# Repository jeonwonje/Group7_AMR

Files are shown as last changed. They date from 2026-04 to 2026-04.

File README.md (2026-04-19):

# Group 7 — Autonomous Mobile Robot (AMR)

> CDE2310 Engineering Systems Design · AY25/26 Semester 2 · NUS EDIC

A **TurtleBot3 Burger (MeowthBot)** ROS 2 Humble workspace for the CDE2310 warehouse delivery mission. The robot autonomously explores a maze using LiDAR-based SLAM, detects AprilTag delivery stations, docks via geometric visual servoing, and delivers ping-pong balls using a servo-driven rack-and-pinion launcher.

---

## System Design Document

The full SDD is split across eight files under [`docs/`](docs/) — one per G2 section. Start with the ConOps, skim the HLD, and jump into the subsystem / ICD detail as needed.

| § | Document | Covers |
|---|---|---|
| 1 | [Requirements Specification](docs/reports/requirements_specification.md) | FRs, NFRs, constraints, traceability |
| 2 | [Concept of Operations](docs/reports/conops.md) | Mission overview, operational scenarios, design selection, risks |
| 3 | [High-Level Design](docs/reports/high_level_design.md) | Architecture, data flow, hardware-software mapping, design decisions |
| 4 | [Subsystem Design](docs/reports/subsystem_design.md) | Navigation, perception, docking, delivery, mission coordination, search |
| 5 | [Interface Control Document](docs/reports/interface_control_document.md) | ROS 2 topics / services / actions, TF tree, hardware interfaces, network |
| 6 | [Software Development](docs/reports/software_development.md) | Environment, repo layout, branch policy, conventions, dependencies |
| 7 | [Testing](docs/reports/testing_documentation.md) | Strategy, integration tests, FAT, traceability, known issues |
| 8 | [End User Documentation](docs/end_user_doc/EndUserDocumentation_Group7.md) | Printed 5-page operator hand-in for the final mission |

### Hardware & Manufacturing

- [Hardware README](hardware/README.md) — mechanical design, CAD version history, materials (maintained by Daniel).
- [Manufacturing Guide](docs/MANUFACTURING.md) — Bambu Lab P2S print workflow for the team's `.3mf` files.

### Project Meta

- [`CHANGELOG.md`](CHANGELOG.md) — release history (SemVer).
- [`CLAUDE.md`](CLAUDE.md) — repo conventions for AI assistants.
- [`AGENT_GIT_GUIDE.md`](AGENT_GIT_GUIDE.md) — quick AI git reference.

---

## Quick start

```bash
# one-time build
source /opt/ros/humble/setup.bash
cd ~/Group7_AMR
colcon build
source install/setup.bash

# RPi (on the robot)
ros2 launch apriltag_docking apriltag_dock_pose_publisher.launch.py &
ros2 run CDE2310_AMR_Trial_Run delivery_server &
ros2 launch turtlebot3_bringup robot.launch.py

# Laptop (base station, same network)
export TURTLEBOT3_MODEL=burger
ros2 launch CDE2310_AMR_Trial_Run full_mission.launch.py
```

See the [End User Documentation](docs/end_user_doc/EndUserDocumentation_Group7.md) §2 for the full deployment sequence and FAT checklist.

---

## Team

| Member | Role | Branch |
|---|---|---|
| Jeon Won Je | Lead — final system integration, nav tuning, manufacturing | `dev/jeon` |
| Shashwat Gupta | Mission coordinator, docking, perception | `dev/shashwat` |
| Kuga | Navigation core | `dev/kuga` |
| Clara Ong | Delivery server, perception | `dev/clara` |
| Daniel Yow | Mechanical subsystem (hardware, CAD, manufacturing docs) | `dev/daniel` |

---

*CDE2310 · NUS College of Design and Engineering · AY25/26*

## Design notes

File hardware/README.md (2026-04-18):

# Hardware <!-- omit in toc -->

## Table of contents <!-- omit in toc -->
- [Overview](#overview)
  - [System Description](#system-description)
  - [Design Objectives](#design-objectives)
- [Initial concept development](#initial-concept-development)
  - [Rack and half pinion](#rack-and-half-pinion)
- [Design iterations](#design-iterations)
  - [Version 1.0.0 - first design](#version-100---first-design)
  - [Version 2.0.0 - servo integrated into launcher](#version-200---servo-integrated-into-launcher)
  - [Version 2.1.0 - bearing supports for rack and pinion](#version-210---bearing-supports-for-rack-and-pinion)
  - [Version 2.2.0 - clutch bearing reset](#version-220---clutch-bearing-reset)
  - [Final Performance summary](#final-performance-summary)
- [Key mechanism explanations](#key-mechanism-explanations)
  - [Rubber band vs Spring](#rubber-band-vs-spring)
  - [Clutch bearing reset](#clutch-bearing-reset)
  - [Rack and pinion engagement](#rack-and-pinion-engagement)
- [Materials and Components](#materials-and-components)
- [Limitations and application specific modifications](#limitations-and-application-specific-modifications)
  - [Launcher System](#launcher-system)

## Overview

This repository contains the CAD models for the payload
and mounting systems used in the AMR.

### System Description

The payload system consists of:

1. Mounting plate 
2. Camera Mount  
3. Launcher
4. Launcher mount 
5. Ball feeder

---

### Design Objectives

- Maintain robot size as much as possible
- Ensure unobstructed LiDAR view
- Position camera at optimal location for docking
- Minimize overall center of gravity
- Ensure repeatability of launcher

---
## Initial concept development

### Rack and half pinion

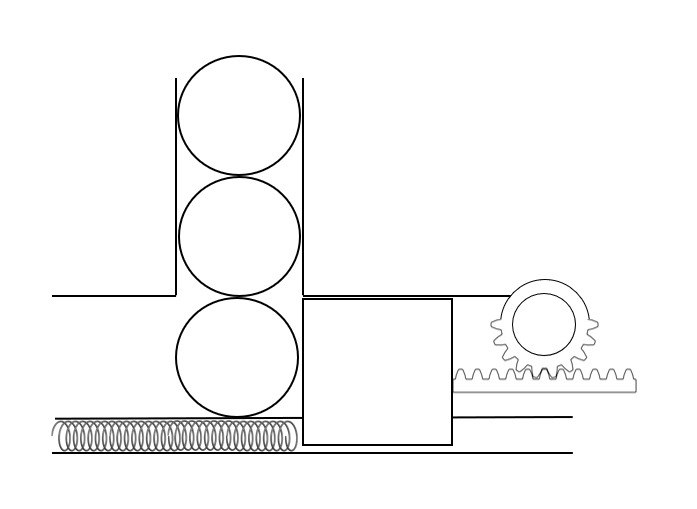
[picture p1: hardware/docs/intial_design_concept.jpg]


Concept Description

The proposed concept used a rack and half-pinion mechanism powered by a continuous rotation servo motor.

At the beginning of each cycle:

- The pinion rotates and engages the rack.
- The rack is pulled backward, retracting the plunger.
- As the plunger retracts, a ball falls into the loading position.

Once the pinion reaches the end of its rotation:

- The rack is released.
- Stored elastic energy in the rubber band drives the plunger forward.
- The ball is launched.

After launch:

- The plunger returns to its forward position.
- This forward position temporarily blocks the next ball from loading prematurely.
- This allows controlled loading of one ball per cycle.

This mechanism enabled both loading and launching to be performed using a single rotational motion.

Rationale for Choosing This Concept:

- This concept was selected due to its ability to combine multiple functions into a single mechanism.

Key advantages included:

- Single actuator operation
- Only one servo motor was required to both retract and release the plunger, reducing system complexity.
- Compact design
- The rack and pinion arrangement allowed the launcher to be positioned within a limited space.
- Low power requirements
- The use of elastic energy storage reduced the need for continuous motor torque during launching.
- Simple mechanical layout
- Fewer moving components reduced potential points of failure.

This made the design suitable for integration into the constrained mechanical layout of the robot.

Identified Limitations of Initial Concept:

Despite its advantages, several limitations were identified during early evaluation.

- Limited launch range
- The amount of stored elastic energy was restricted by the available rack travel distance.
- Potential alignment sensitivity
- Rack and pinion mechanisms require accurate alignment to prevent slipping or uneven wear.
- Dependence on consistent pinion engagement
- Incorrect starting positions could lead to failed engagement or inconsistent loading.

These limitations informed the design changes introduced in later iterations.

## Design iterations
### Version 1.0.0 - first design
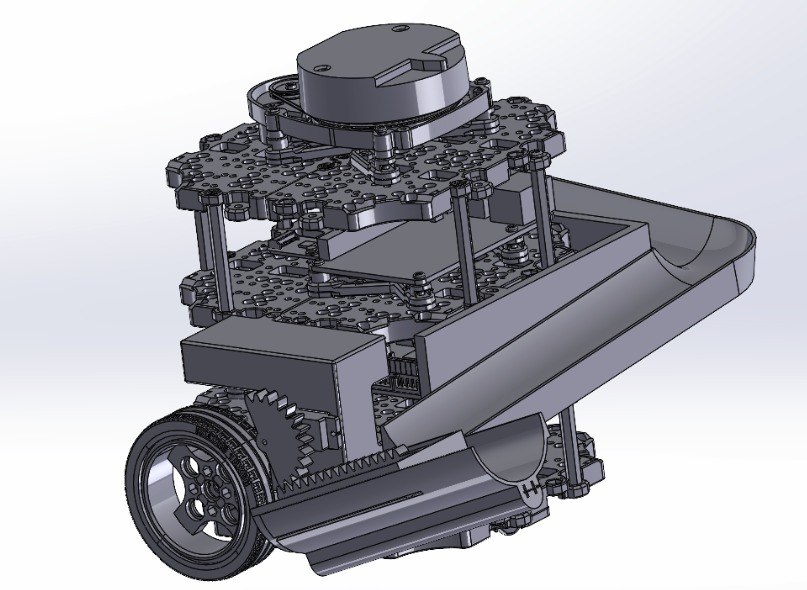
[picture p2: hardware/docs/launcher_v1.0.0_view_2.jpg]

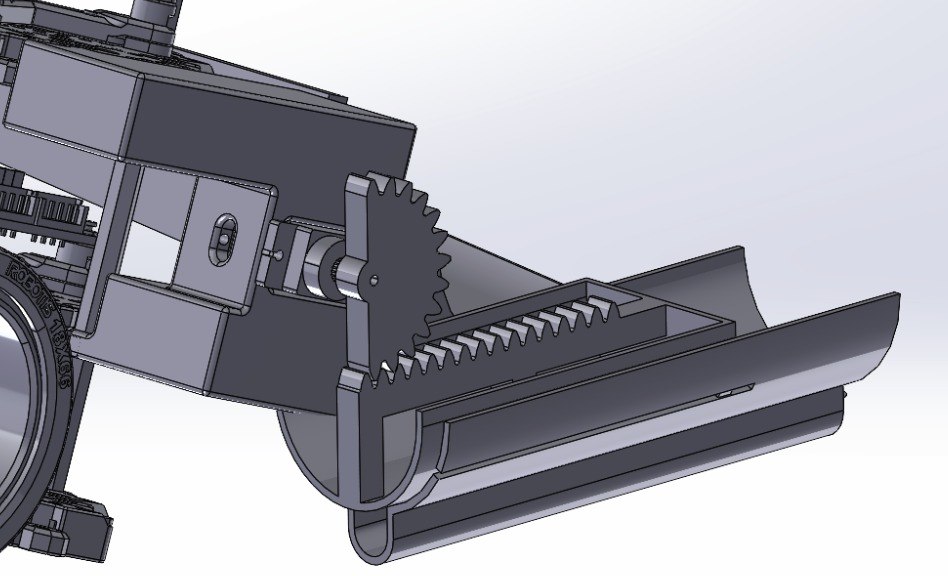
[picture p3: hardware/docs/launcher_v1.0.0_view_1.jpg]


Problems Observed:

- The servo was mounted directly to the chassis instead of the launcher assembly.
This caused structural flexing during operation, leading to misalignment between the pinion and rack and resulting in slipping.
- Mounting the servo on the chassis also prevented independent testing of the launcher mechanism.
This slowed down development because launcher testing depended on Turtlebot availability.
- Nav team feedback that current poition of launcher would make moving through the maze challenging.

### Version 2.0.0 - servo integrated into launcher
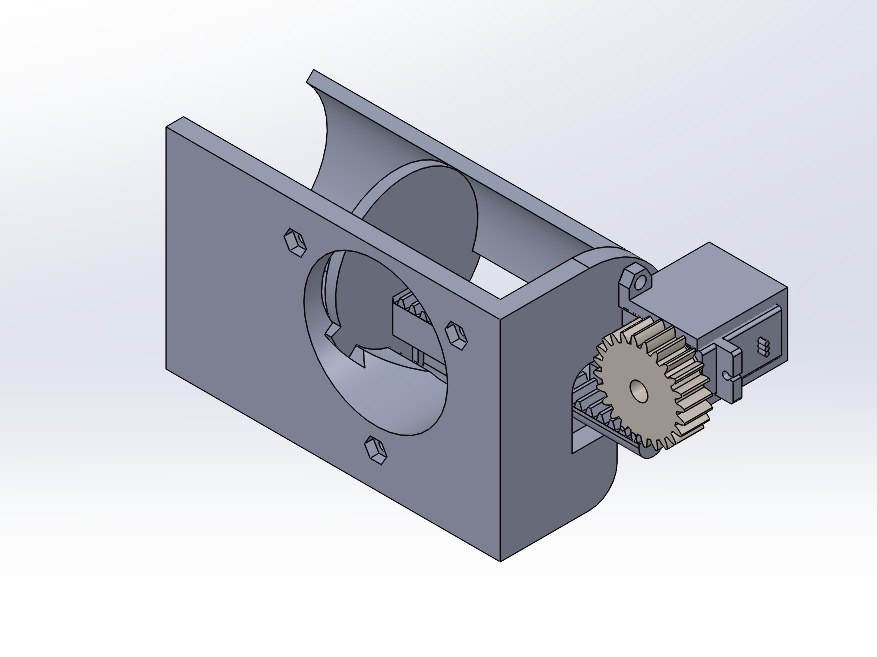
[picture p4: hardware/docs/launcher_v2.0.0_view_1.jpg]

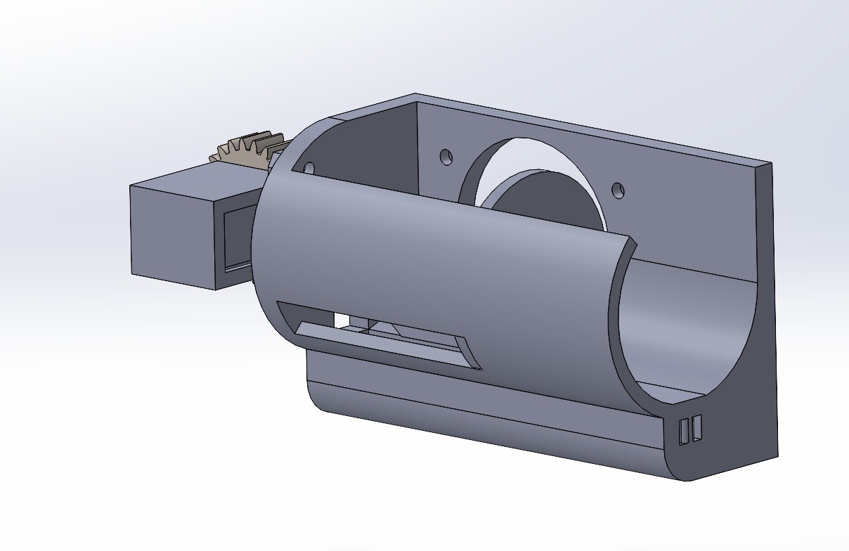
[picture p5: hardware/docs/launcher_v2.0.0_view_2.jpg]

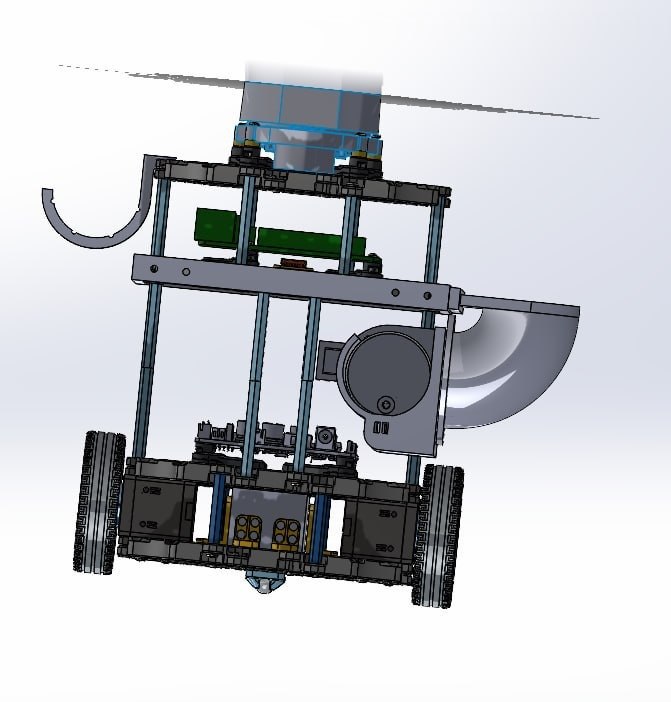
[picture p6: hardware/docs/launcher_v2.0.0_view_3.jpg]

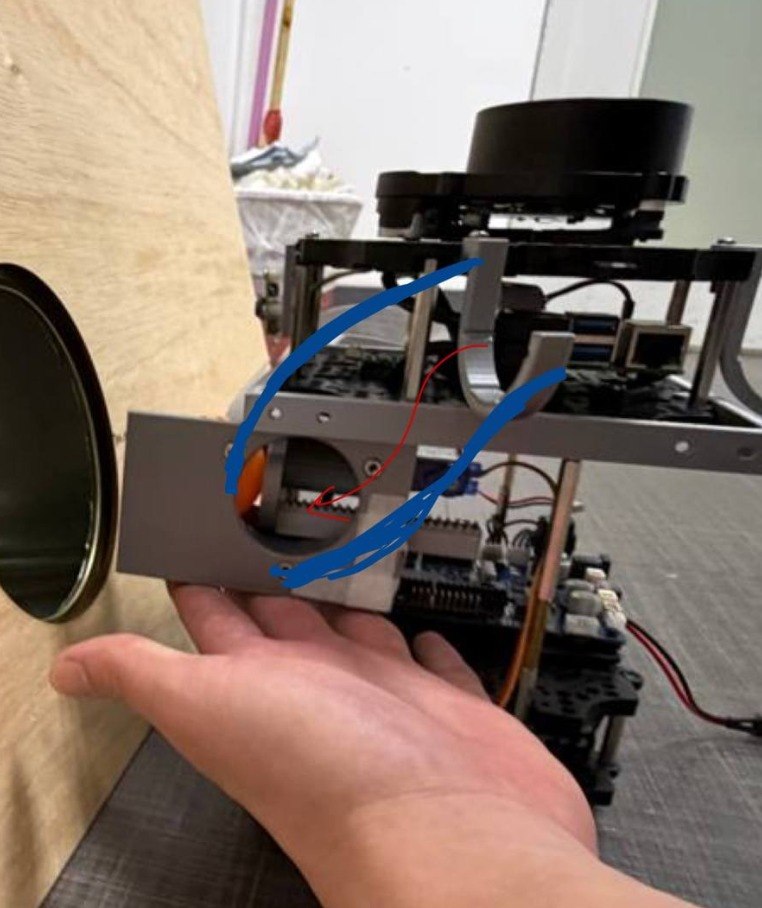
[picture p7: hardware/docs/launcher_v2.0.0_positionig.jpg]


Changes from Previous Version:

- Mounted the servo directly onto the launcher assembly to reduce structural flex.
- Repositioned the launcher between waffle plates instead of side-mounted to improve structural support.

Problems Observed:

- Launcher achieved poor range, indicating insufficient stored energy and inefficiencies.
- The plunger occasionally became stuck and failed to release.
- Pinion slipping issue persisted due to insufficient constraint of both rack and pinion.
- When assembling putting plunger into tube was challenging.

Possible Root Causes:

- Rack alignment was not properly constrained.
- Pinion support was only provided on one side, allowing tilting under load.
- The plunger face and rack being one piece makes it hard and awkward to fit into the tube.

### Version 2.1.0 - bearing supports for rack and pinion
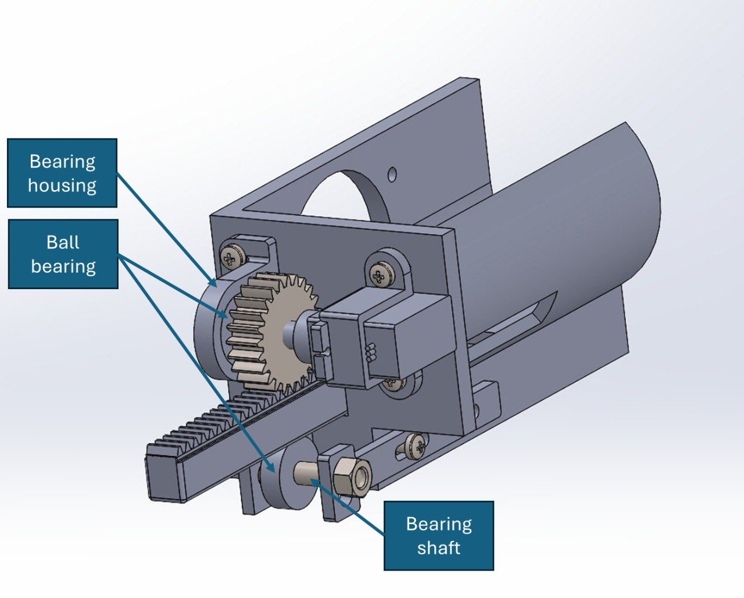
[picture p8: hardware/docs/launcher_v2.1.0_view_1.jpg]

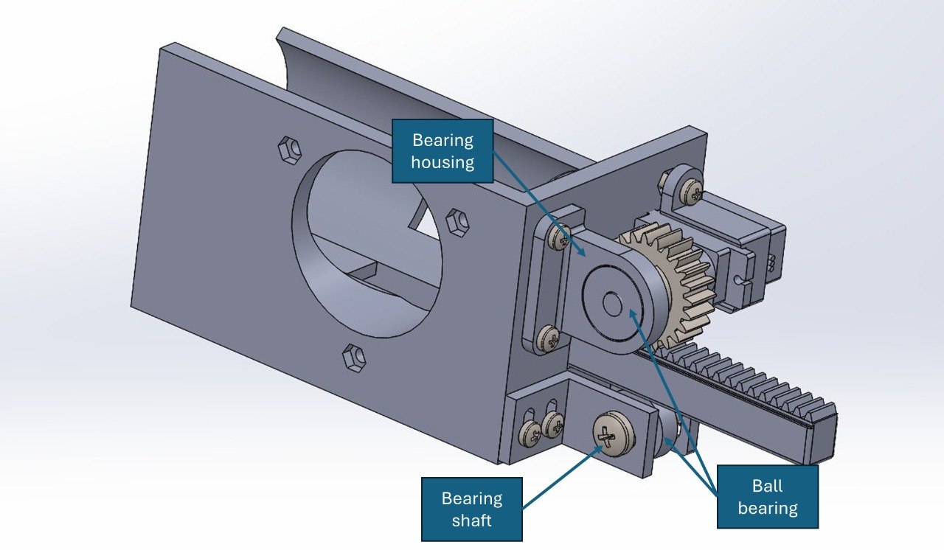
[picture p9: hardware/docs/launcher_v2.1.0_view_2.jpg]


Changes from Previous Version:
- Added a ball bearing and housing to support the pinion from the opposite side, improving alignment and reducing tilting.
- Added a shaft and bearing system beneath the rack to prevent downward movement during loading.
- Replaced the spring with a rubber band to increase stored elastic energy while keeping motor torque below stall limits.
- Split plunger into plunger face and rack to be fastened together with M3 screw.

Problems Observed:
- Pinion position after each launch is inconsistent.

Possible root causes:
- Continuous servo does not have rotation control
- Tuning each rotation by time is difficult and impractical
- Rotation error after each launch stacks up 

### Version 2.2.0 - clutch bearing reset
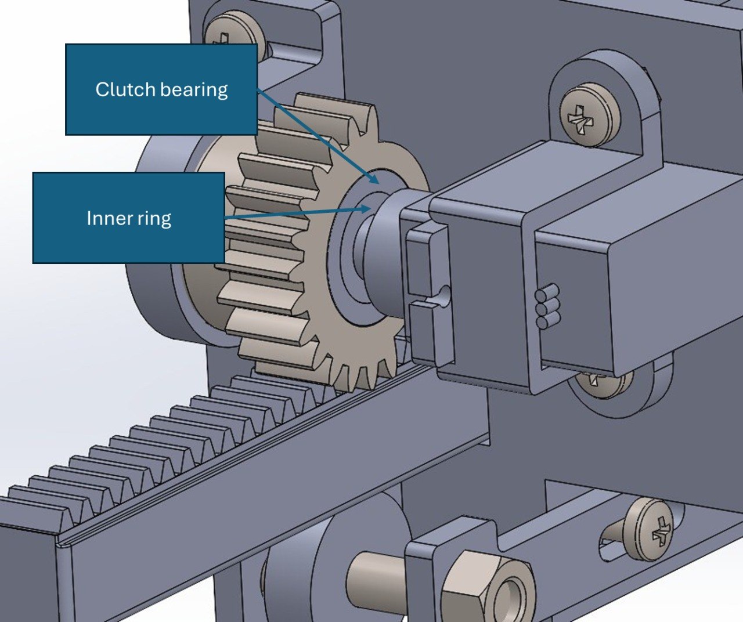
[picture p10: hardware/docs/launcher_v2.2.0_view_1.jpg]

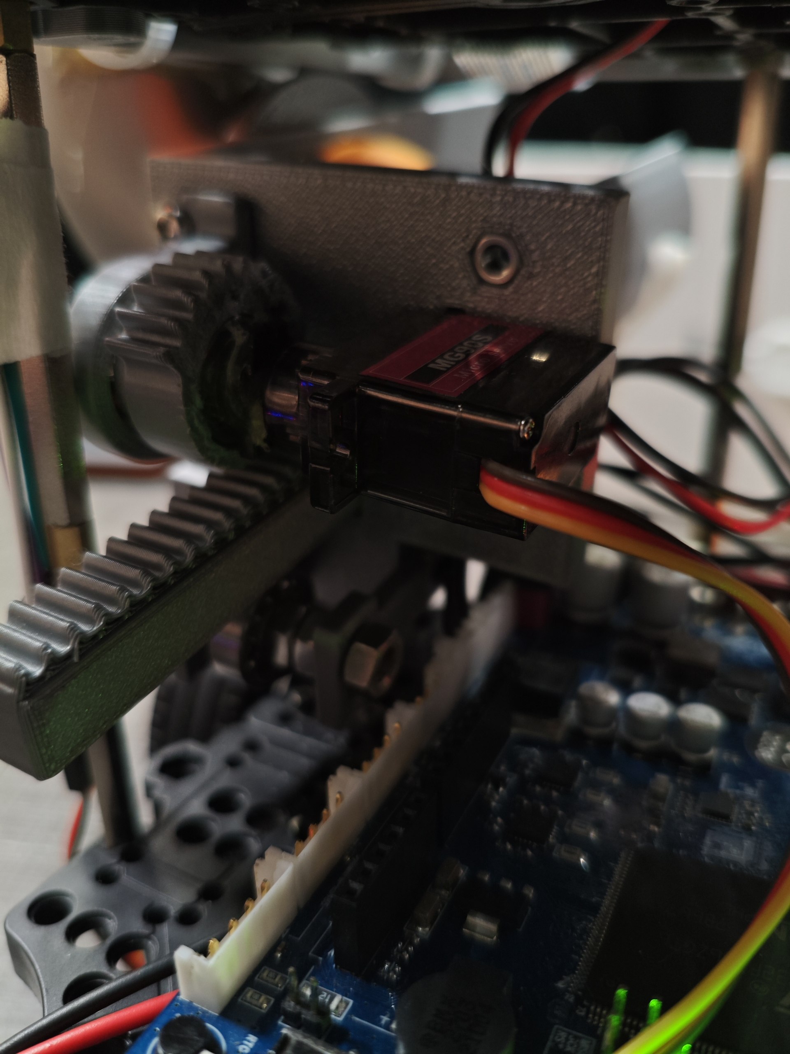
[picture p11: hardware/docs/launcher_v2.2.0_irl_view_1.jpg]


Changes from Previous Version:

- Added a clutch bearing and inner ring to allow the pinion to reset to a consistent starting position after each launch.
- Modified the pinion design to house the clutch bearing internally.

Problems Observed:

- Engagement between the pinion and rack occurred at inconsistent positions.
- In some cases, the plunger was already fully retracted before rack was released

Fix Implemented:

- Added washers between the plunger face and rack to shift the rack starting position.

Result After Fix:

- Engagement between pinion and rack became consistent.

### Final Performance summary
- No slippage between rack and pinion during repeated testing
- Consistent engagement between rack and pinion
- Pinion achieves consistent reset position
- Plunger motion is smooth and repeatable

## Key mechanism explanations

### Rubber band vs Spring
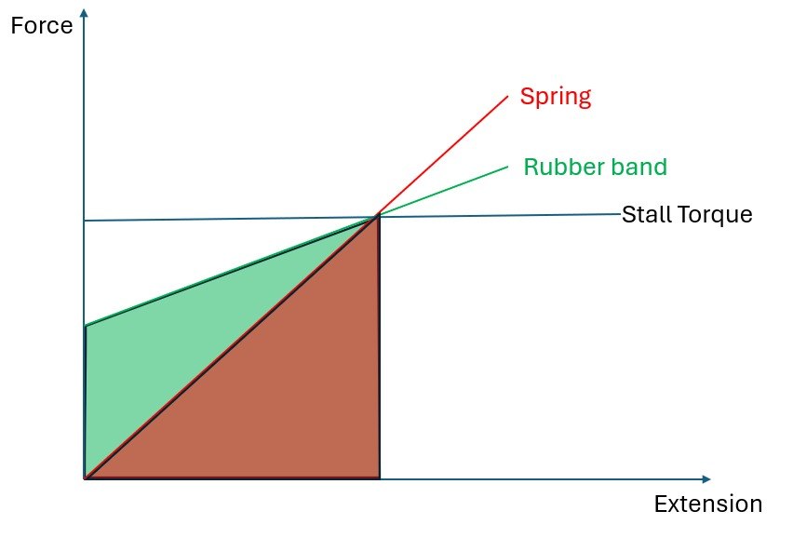
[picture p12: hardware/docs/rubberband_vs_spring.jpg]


Rubber band can be already be streched when the plunger is in the fowardmost position allowing us to store more energy while keeping within the stall torque.

### Clutch bearing reset
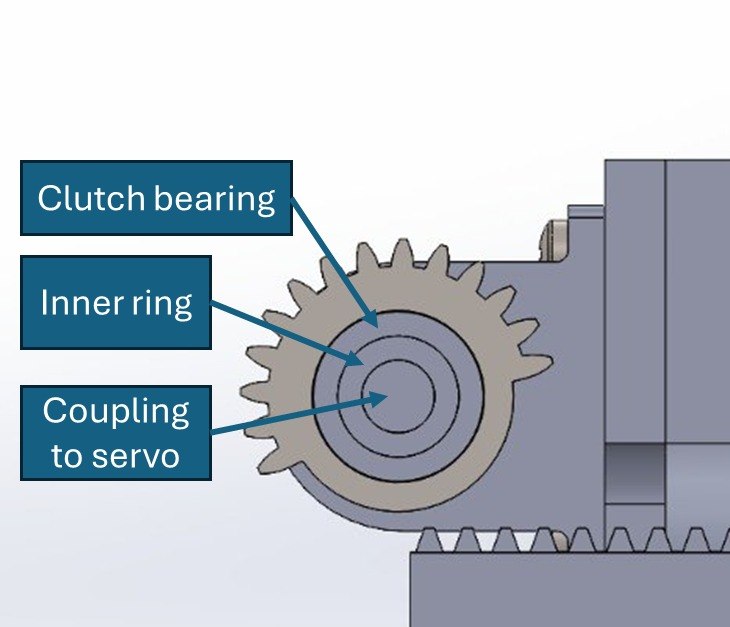
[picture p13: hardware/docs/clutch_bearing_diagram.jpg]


Problem: Loss of Positional Control in Continuous Servo Motors

The TowerPro MG90 Servo Motor was modified to allow continuous rotation.
As a result, positional control was lost, and the PWM signal controlled motor speed instead of angular position.

This created several issues:

- The angular position of the pinion before each launch became unpredictable.
- The time taken for one full rotation varied due to changing conditions such as rubber band tension, friction, and mechanical load.
- Small timing errors accumulated after each cycle.
- This caused inconsistent pinion starting positions, leading to unreliable launches.
- In some cases, this resulted in failed launches or multiple balls being released unintentionally.

Solution: Use of a Clutch Bearing for Passive Reset
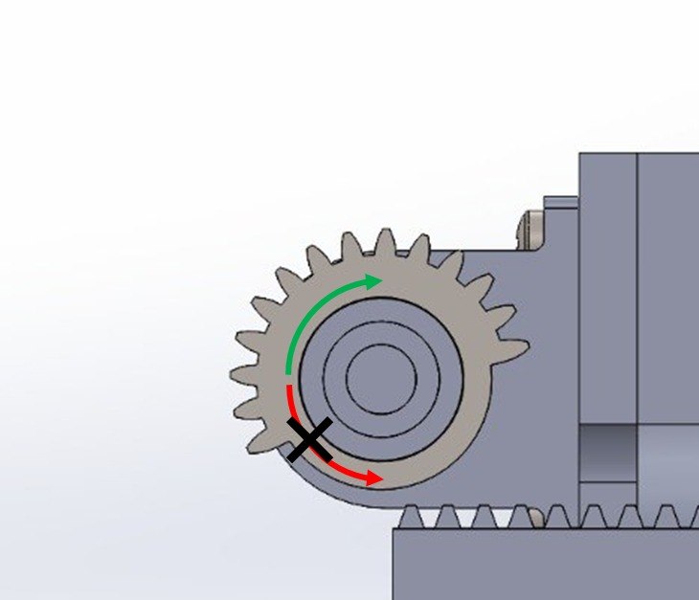
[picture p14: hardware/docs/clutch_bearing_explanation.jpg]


A clutch bearing was introduced to allow the pinion to reset to a consistent angular position after every launch cycle.

A clutch bearing allows rotation in one direction while locking in the opposite direction.

This directional locking property was used to create a passive mechanical reset mechanism, removing reliance on timing accuracy.

Working Principle:
1. Rack Loading Phase (Clockwise Rotation)
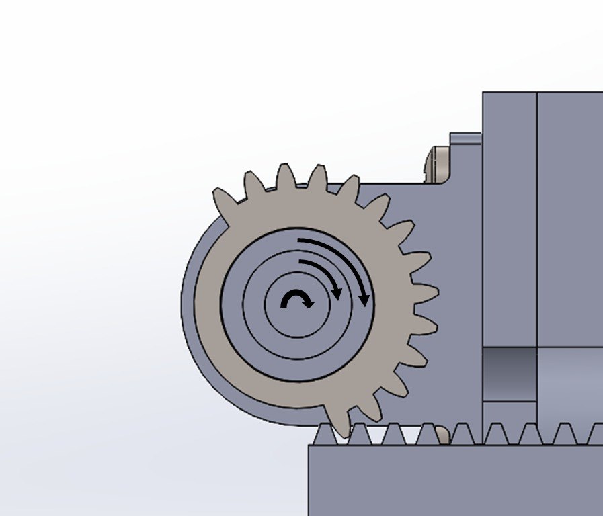
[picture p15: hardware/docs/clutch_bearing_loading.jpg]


During loading:
- The servo rotates clockwise.
- The clutch bearing locks in this direction.
- Torque is transferred from the servo to the pinion.
- The pinion engages the rack and pulls it backward.
- Elastic energy is stored in the rubber band.
- The rack is released at the end of the pinion as per normal.

2. Reset Phase (Anticlockwise Rotation)
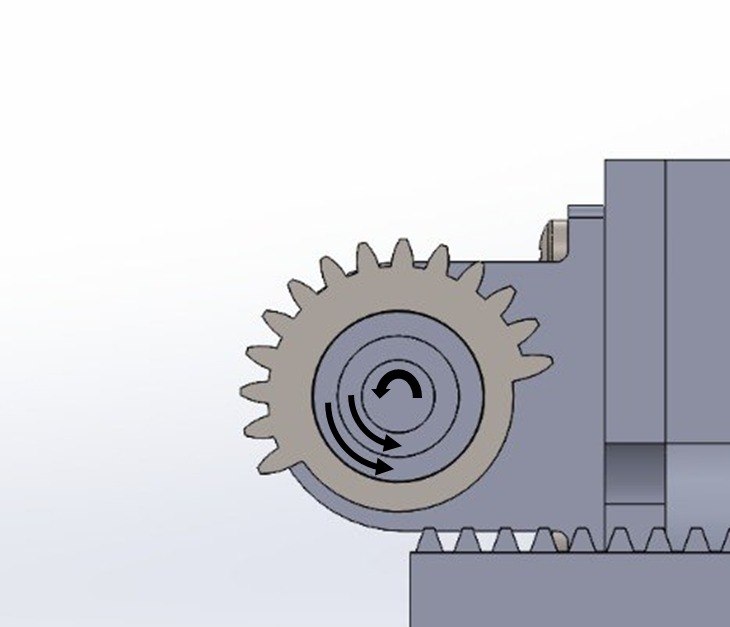
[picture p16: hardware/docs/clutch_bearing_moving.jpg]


After launch:

- The servo rotates anticlockwise.
- The clutch bearing allows free rotation in this direction.
- The pinion rotates together with the servo initially.
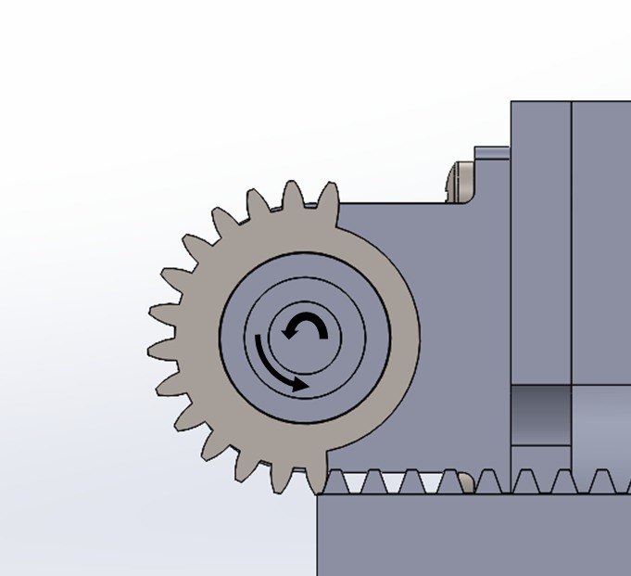
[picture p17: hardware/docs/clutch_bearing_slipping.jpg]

- Once the pinion reaches its reset position, the clutch slips internally.
- This allows the pinion to remain stationary while the servo continues to rotate freely.

This ensures that:

- The pinion always returns to the same angular position.
### Rack and pinion engagement
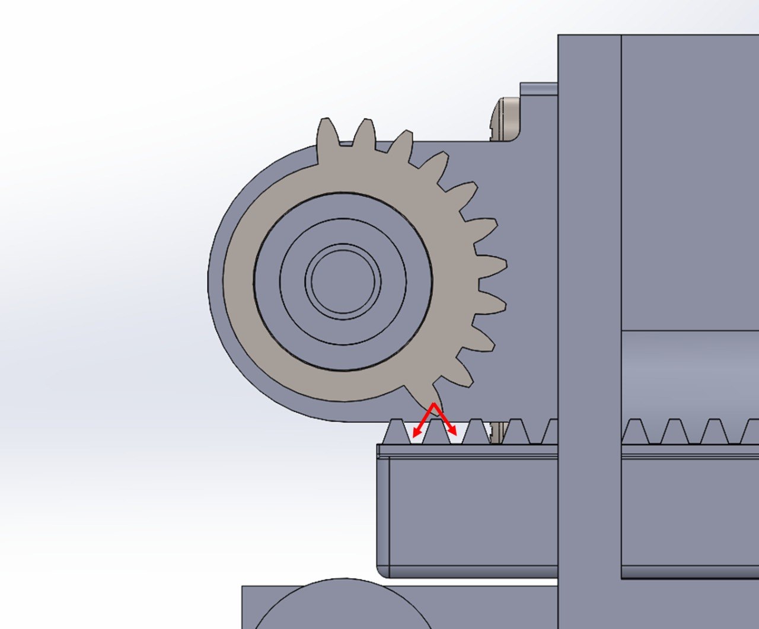
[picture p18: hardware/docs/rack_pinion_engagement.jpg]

Problem: Inconsistent Rack–Pinion Engagement

The initial forward position of the rack caused inconsistent engagement with the pinion gear.

Due to the rack starting position:

- The pinion did not consistently engage the same tooth on the rack.
- Depending on the angular position of the pinion, engagement occurred randomly between adjacent teeth.

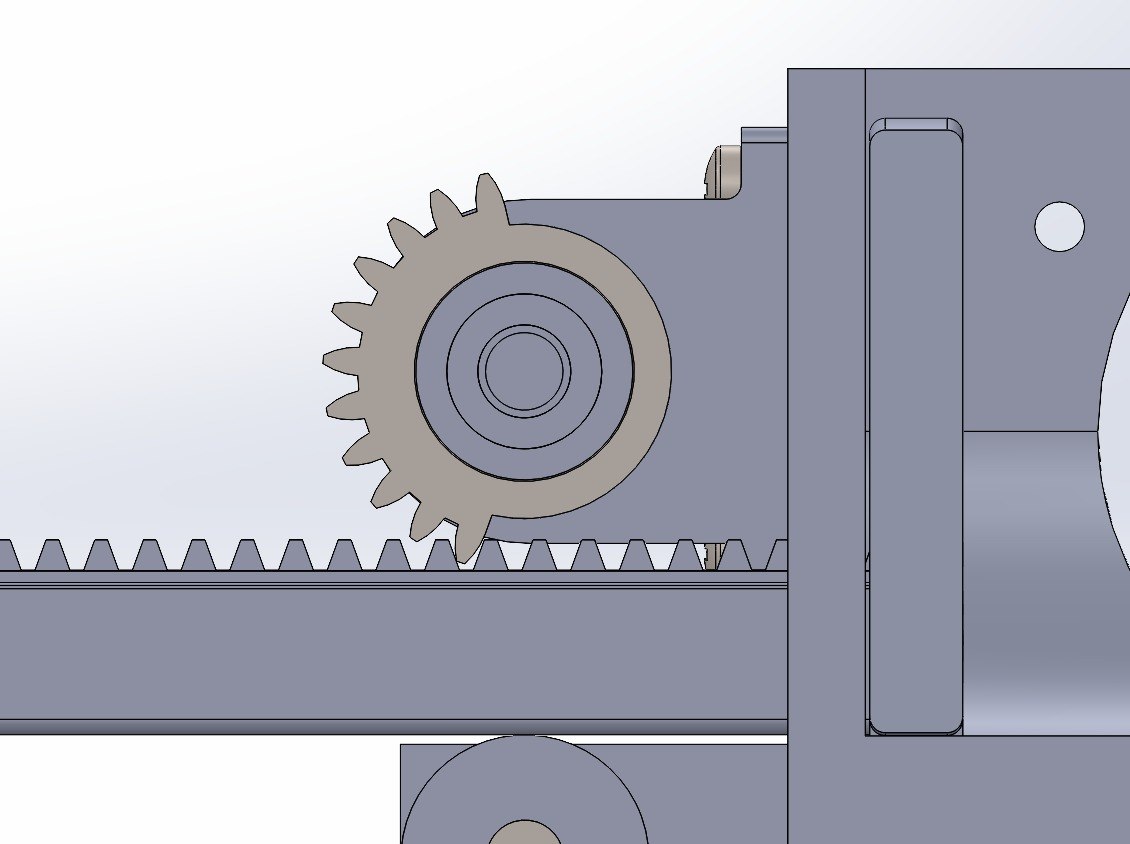
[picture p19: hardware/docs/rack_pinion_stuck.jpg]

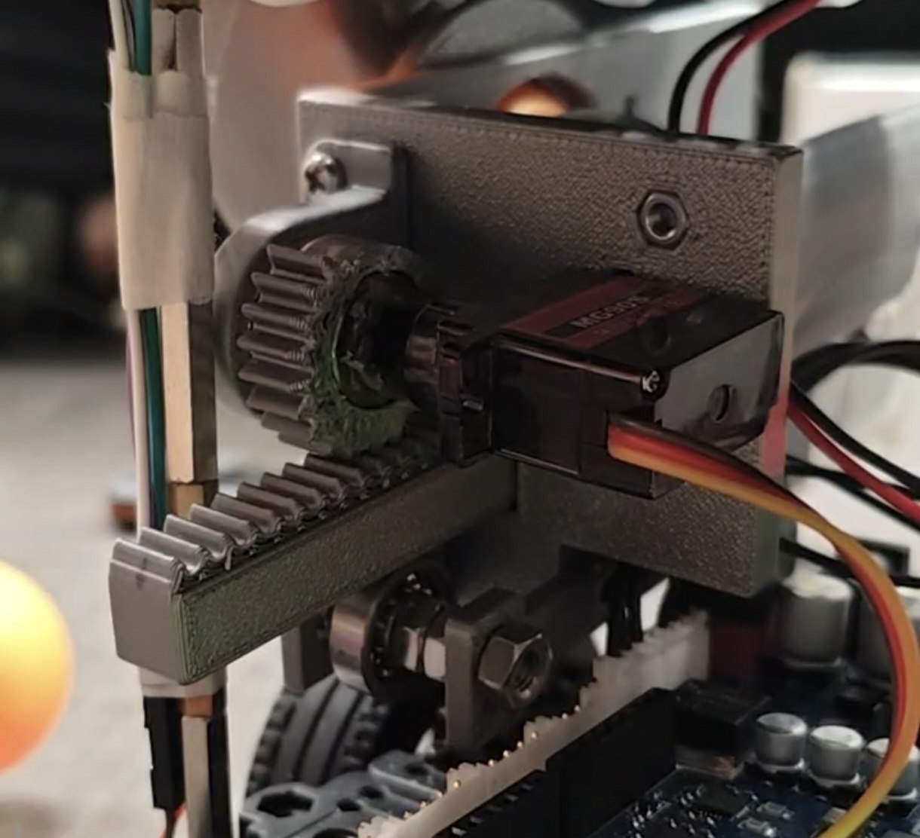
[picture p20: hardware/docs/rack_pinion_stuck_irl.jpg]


As a result:

- There were instances where the plunger got stuck and did not fire.

Fix Implemented: Rack Position Adjustment Using Washers

- To correct the engagement alignment, washers were added between the rack and the plunger face.

This modification:

Shifted the rack slightly backward relative to the pinion.
Adjusted the rack starting position to align properly with the pinion teeth.
Ensured that the pinion consistently engaged the same rack tooth during each cycle.

The number of washers was incrementally adjusted until consistent engagement was achieved.

## Materials and Components

The launcher system consisted of both custom-manufactured and purchased components.

Custom-Manufactured Components:
- Rack
- Pinion housing
- Plunger body
- Ball feeder holders
- Launcher tube

These components were manufactured using 3D printing with the following settings:
- layer height
- infill density
- etc

Purchased Components:
- Ball bearings
- Clutch bearing
- Continuous servo motor
- Aluminium wire (ball feeder)

## Limitations and application specific modifications

### Launcher System
Limitation 1 — Wear of Self-Forming Threads

- The threads used to connect the rack to the plunger face are self-forming threads.

Explanation:
- This connection experiences repeated loading and unloading during each launch cycle. As a result, the self-forming threads are subjected to cyclic fatigue and may gradually wear or loosen over time.

Impact:
- Thread wear may lead to reduced structural integrity and eventual loosening of the rack–plunger connection, reducing system reliability.

Recommended Modification:
- Replace the self-forming threads with heat-set threaded inserts to improve durability and maintain thread strength over repeated cycles.

Limitation 2 — Open Launcher Tube

- The launcher tube was designed to be fully open to allow visual observation during development and debugging.

Explanation:
- While this design simplified troubleshooting, it left the internal components exposed to external debris.

Impact:
- Foreign objects entering the launcher tube were observed to interfere with plunger motion, occasionally affecting launcher performance.

Recommended Modification:
- For deployment in real environments, the launcher tube should be redesigned as a fully enclosed structure to prevent debris ingress and improve reliability.

Ball Feeder System
Limitation 3 — Deformation of Aluminium Wire Feeder

- The ball feeder is currently constructed using aluminium wire supported by 3D-printed holders.

Explanation:
- Aluminium wire is relatively malleable and can deform under repeated loading or accidental contact.

Impact:
- Any deformation alters the alignment of the feeder path, which reduces the consistency of ball feeding and increases the likelihood of jams.

Recommended Modification:
- Replace the aluminium wire feeder with a fully 3D-printed feeder structure designed with higher rigidity and consistent geometry.

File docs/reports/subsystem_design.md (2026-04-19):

# Subsystem Design

| Field | Value |
|---|---|
| Document ID | AMR-SSD-001 |
| Version | 1.0 |
| Date | 2026-04-13 |
| Author(s) | Group 7 — Jeon, Shashwat, Kuga, Clara, Daniel |
| Module | CDE2310 Engineering Systems Design |
| Status | Baselined for G2 |

---

## 1  Purpose

This document provides detailed design information for each subsystem of the
Group 7 AMR: navigation, perception, docking, delivery, and mission coordination.
For each subsystem the document specifies purpose, key algorithms, tunable
parameters, state machines, and ROS 2 interfaces.

---

## 2  Subsystem Descriptions

### 2.1  Navigation Subsystem

#### 2.1.1  Exploration — `auto_explore_v2`

**Owner:** Kuga (navigation core)

**Purpose:** Autonomously cover the maze by repeatedly selecting and navigating
to the most promising frontier.

**Nodes:**

| Node | File | Role |
|---|---|---|
| `auto_explore` | `find_frontiers.py` | BFS frontier detection + clustering |
| `score_and_post` | `score_and_post.py` | Frontier scoring, Nav2 goal dispatch |

**Algorithm — Frontier Detection (find_frontiers.py):**

1. Subscribe to `/map` (OccupancyGrid).
2. Build a dictionary `(x, y) → cell_value` for the full grid.
3. For each free cell (value = 0), check 4-connected neighbours.
   If any neighbour is unknown (value = −1), the cell is a frontier.
4. Flood-fill (BFS) to cluster contiguous frontier cells.
   Clusters smaller than `FRONTIER_MIN_SIZE` (3) are discarded.
5. Publish cluster centroids and the BFS distance transform on
   `frontiers` and `bfs_distance_transform` topics (JSON-encoded).

**Algorithm — Frontier Scoring (score_and_post.py):**

1. For each cluster centroid, compute:
   - `bfs_dist`: cost from BFS distance transform (lower is closer).
   - `size`: number of cells in the cluster (larger frontier = more information).
2. Score = f(size, bfs_dist) — larger clusters closer to the robot are preferred.
3. Optionally pre-flight the top candidate via `ComputePathToPose` action.
   If the path is blocked (occupancy ≥ 51), discard and try the next candidate.
4. Post the winning goal to Nav2 via `NavigateToPose` action.
5. On completion or timeout, re-score and repeat.
6. When all frontiers fall below the scoring floor, publish an
   `EXPLORATION_COMPLETE` status (not currently emitted by the implementation
   — see §2.5 "Known gap"; the mission FSM relies on the exploration timeout
   instead).

**Toggle service:** `toggle_exploration` (SetBool) — the mission coordinator
pauses/resumes exploration during docking/delivery.

**Parameters:**

| Parameter | Value | Unit  | Description |
|---|---|---|---|
| FRONTIER_MIN_SIZE | 3 | cells | Minimum cluster size to consider |
| PATH_BLOCKED_OCC_MIN | 51 | — | Occupancy threshold for blocked path |
| PREFLIGHT_TIMEOUT_SEC  | 10.0  | s | Timeout for ComputePathToPose check  |

---

*Note: A custom Nav2-free navigation package (`amr_nav`) was explored during
development but ultimately removed in favour of the Nav2-based stack (see
CHANGELOG 1.1.0). Its Dijkstra/A* algorithms and earlier pathfinding unit tests
are recoverable from git history (commit `044e346`).*

---

### 2.2  Perception Subsystem — `apriltag_docking`

**Owners:** Shashwat and Clara (shared — integration, calibration, configuration)

**Purpose:** Detect tag36h11 AprilTag markers in the RPi camera feed, compute
6-DOF poses, and broadcast the resulting transforms plus Nav2-consumable
PoseStamped topics so mission, docking, and delivery nodes can react to tag
geometry.

**Provenance:** `apriltag_docking` is a team-authored ament_cmake (C++) ROS 2
package located at `src/apriltag_docking/`. It wraps upstream dependencies
(`camera_ros`, `image_proc`, `apriltag_ros`) into a single zero-copy
composable container and adds two bespoke elements: per-station static
`nav2_dock_target_{id}` frames, and a C++ `detected_dock_pose_publisher` node
that republishes TF lookups as `geometry_msgs/PoseStamped` at 10 Hz for Nav2
consumption. The `detected_dock_pose_publisher.cpp` node is adapted from
Addison Sears-Collins' Dec 2024 tutorial (attribution preserved in source).

**Pipeline (single composable container `apriltag_vision_container`, intra-process comms):**

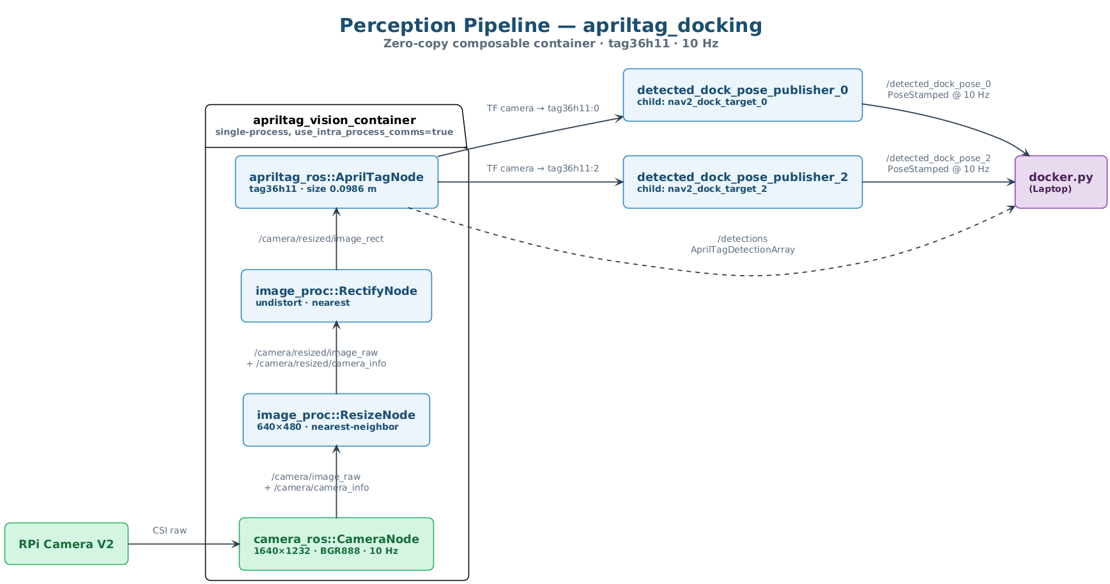
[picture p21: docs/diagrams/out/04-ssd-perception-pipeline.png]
Figure 4 — Perception Pipeline


*Figure 4 — `apriltag_docking` zero-copy composable container on the RPi. Source: [`../diagrams/04-ssd-perception-pipeline.puml`](../diagrams/04-ssd-perception-pipeline.puml).*

Standalone TF bridges launched alongside the container:
- `base_link → camera_link` (static, x=0.09, y=0.05, z=0.097).
- `camera_link → camera` (static optical rotation, yaw=-π/2, roll=-π/2).

**Downstream consumers:**
- `docker.py` subscribes to `/detected_dock_pose_{0,2}` for geometric servoing.
- `delivery_server_consolidated.py` subscribes to `/detections` for Station B
  reactive fires against tag36h11 ID 3.
- `mission_coordinator_v3.py` monitors the TF tree (`camera → tag36h11:{0,2}`)
  with a 0.5 s staleness threshold before acting on a tag.

**Configuration** (`src/apriltag_docking/config/apriltags_36h11.yaml`):

| Parameter | Value | Description |
|---|---|---|
| Tag family | tag36h11 | Per mission brief. |
| Tag size | 0.0986 m | Physical side length (as measured on the printed tag).|
| decimate | 2.0 | Detector down-sample factor. |
| threads | 1 | Detector worker threads (single-threaded on RPi). |
| refine | true | Edge refinement enabled. |
| max_hamming | 0 | No Hamming-bit correction (strict IDs). |
| Camera intrinsics | Calibrated | Produced via `camera_calibration`; loaded by `camera_ros`. |
| Broadcast tag IDs | 0, 2 | Static and dynamic docking stations (TF frames). |
| Detection-only tag ID  | 3 | Moving target on Station B rail; present in `/detections` only — no TF frame is broadcast. |

**Innovation vs vanilla `apriltag_ros`:** the fused composable pipeline
(resize → rectify → detect with zero-copy intra-process transport), the
per-station `nav2_dock_target_{id}` frames that encode the dock approach
geometry, and the C++ `detected_dock_pose_publisher` that converts TF lookups
into Nav2-consumable `PoseStamped` topics.

**Robustness:** Mission-side consumers guard against stale detections with a
0.5 s TF age limit and, for docking, a 1.0 s camera-dropout coast window.

---

### 2.3  Docking Subsystem — `CDE2310_AMR_Trial_Run/docker.py`

**Owner:** Shashwat

**Purpose:** Execute precision docking from a staging waypoint to the tag face
using discrete geometric visual servoing.

**Node:** `docking_server` (docker.py)

**Algorithm — Geometric Visual Servoing:**

The docking server replaces continuous PID control with an 8-state discrete
state machine. The input signal is `/detected_dock_pose_{0,2}` (PoseStamped
in the camera optical frame, published at 10 Hz by `apriltag_docking`); the
output is `/cmd_vel` twists plus one Nav2 `NavigateToPose` call per dock.

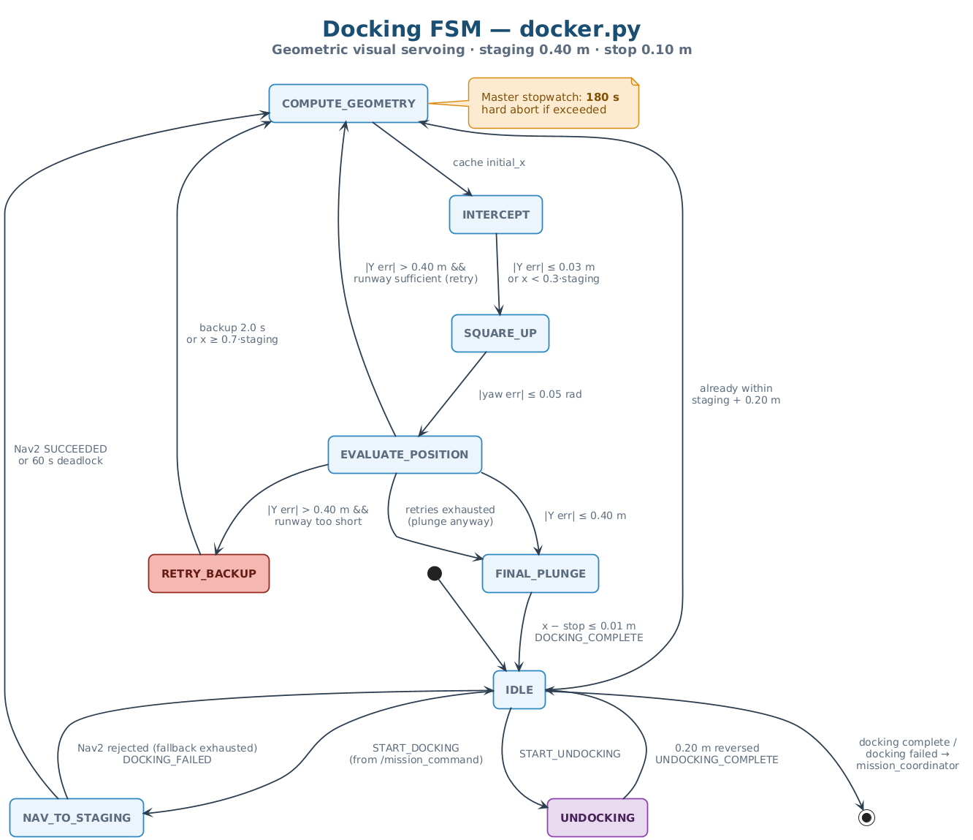
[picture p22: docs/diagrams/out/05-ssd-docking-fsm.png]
Figure 5 — Docking FSM


*Figure 5 — `docker.py` 8-state geometric visual-servoing FSM. Source: [`../diagrams/05-ssd-docking-fsm.puml`](../diagrams/05-ssd-docking-fsm.puml).*

**Parameters:**

| Parameter | Value  | Unit  | Description |
|---|---|---|---|
| staging_distance | 0.40 | m | Nav2 drop-off distance from tag |
| stop_distance | 0.10 | m | Final approach stop from tag |
| intercept_ratio | 0.7 | — | Dynamic lookahead fraction |
| abort_ratio | 0.3 | — | Hard safety boundary fraction |
| intercept_y_tolerance  | 0.03 | m | Centreline alignment tolerance |
| square_yaw_tolerance | 0.05 | rad | Yaw alignment tolerance |
| slow_linear_speed | 0.03 | m/s | Approach speed |
| max_angular_speed | (cap)  | rad/s | Rotation speed cap |
| max_docking_time | 180 | s | Hard timeout for entire sequence |
| sensor_drop_tolerance  | 1.0 | s | Camera dropout coast time |
| fallback_staging_offset| 0.15 | m | Subtracted on Nav2 rejection retry |

**Robustness:**
- Camera dropout: coast on last-known `/detected_dock_pose_N` for up to
  `sensor_drop_tolerance` (1 s).
- Nav2 rejection: subtract `fallback_staging_offset` (0.15 m) and retry once;
  second rejection aborts with DOCKING_FAILED.
- Timeout: abort after `max_docking_time` (180 s) regardless of state.
- Backup: if Y error too large at `EVALUATE_POSITION`, reverse at
  `backup_speed` for `backup_duration`, then return to `COMPUTE_GEOMETRY`
  (up to `max_retries` = 3).

---

### 2.4  Delivery Subsystem

**Owner:** Clara (delivery server + launcher integration)

#### 2.4.1  delivery_server (`CDE2310_AMR_Trial_Run/delivery_server_consolidated.py`)

**Purpose:** Orchestrate ball delivery for both static and dynamic stations.

**Static Station Protocol (tag36h11:0):**
1. Receive `START_DELIVERY` command.
2. Fire ball → wait 4 s → fire → wait 6 s → fire.
3. Publish `DELIVERY_COMPLETE`.

**Dynamic Station Protocol (tag36h11:2):**
1. Receive `START_DELIVERY` command.
2. Subscribe to `/detections` (AprilTagDetectionArray).
3. When tag ID 3 is detected, fire immediately.
4. Enter 4 s cooldown.
5. Repeat until 3 shots fired or `max_dynamic_shots` reached.
6. Publish `DELIVERY_COMPLETE`.

**Parameters:**

| Parameter | Value | Unit | Description |
|---|---|---|---|
| cooldown_seconds | 4.0 | s | Cooldown between dynamic shots |
| max_dynamic_shots  | 3 | — | Maximum shots at dynamic station |
| TARGET_TAG_ID | 3 | — | Tag ID for dynamic station target |

#### 2.4.2  Servo Control (consolidated in delivery_server)

The delivery_server directly controls the MG90 servo via GPIO 12 (hardware PWM)
on the RPi. There is no separate shooter node or `/fire_ball` service.

**Mechanism:** Servo rotates the spur gear, which drives the rack-and-pinion
plunger. The plunger compresses the spring and releases, propelling the ball
out of the barrel via a gravity-fed tube (7-ball capacity).

---

### 2.5  Mission Coordination — `mission_coordinator_v3`

**Owner:** Shashwat. Jeon (robustness patches).

**Purpose:** Central FSM that orchestrates all subsystems and manages the
mission lifecycle.

**State Machine:**

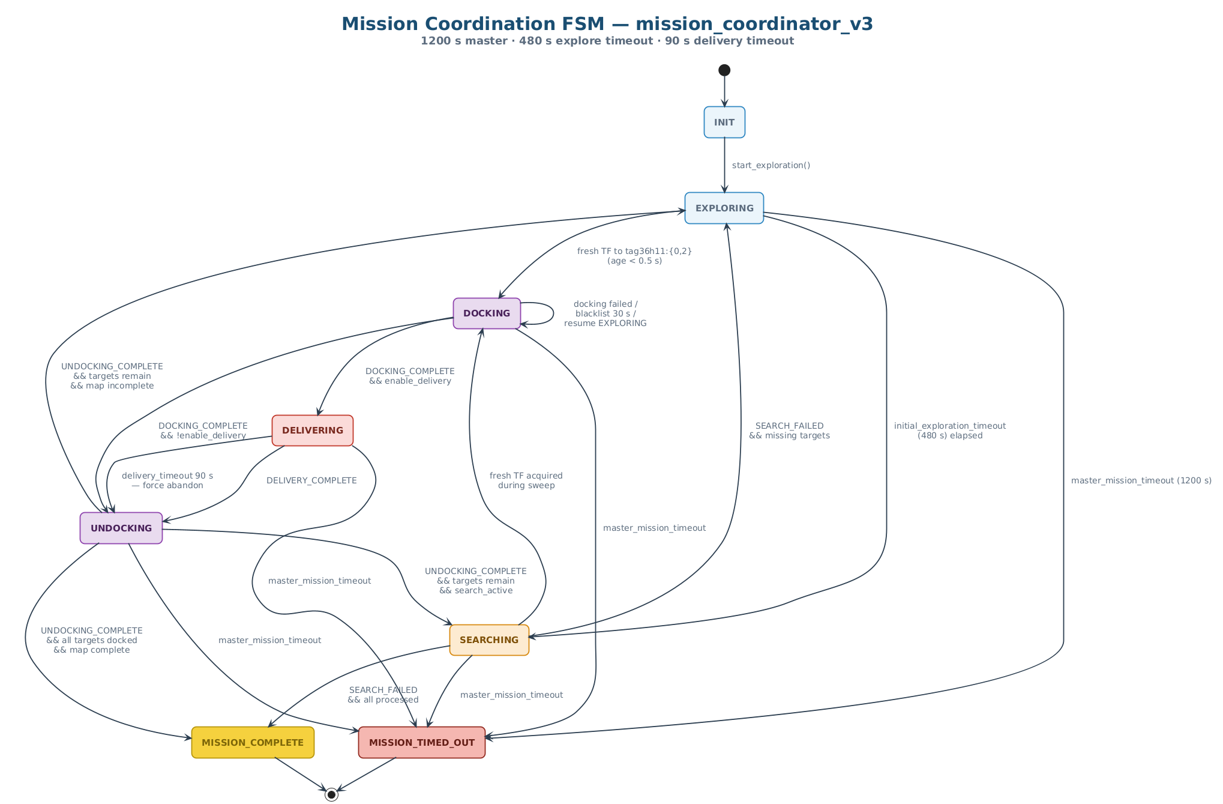
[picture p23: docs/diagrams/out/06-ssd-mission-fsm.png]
Figure 6 — Mission Coordination FSM


*Figure 6 — `mission_coordinator_v3` state machine. Source: [`../diagrams/06-ssd-mission-fsm.puml`](../diagrams/06-ssd-mission-fsm.puml).*

**Key Mechanisms:**

| Mechanism | Implementation |
|---|---|
| Tag monitoring | Poll TF tree at 10 Hz for target tags (`tag36h11:0`, `tag36h11:2`) |
| Staleness filtering | Reject TF transforms older than `stale_tf_threshold` (0.5 s) |
| Blacklisting | HashMap `{tag: expiry_time}`, 30 s duration |
| Clear blacklist | `clear_blacklist` (std_srvs/Empty) client call to `score_and_post`, invoked on exploration resume so previously penalised frontiers become eligible again |
| Exploration toggle | `toggle_exploration` (std_srvs/SetBool) service call to `score_and_post` |
| Command dispatch | JSON on `/mission_command` topic |
| Status listening | JSON on `/mission_status` topic |
| Exploration timeout | `initial_exploration_timeout` (480 s) sets `timeout_search_active = True` and transitions EXPLORING → SEARCHING while un-serviced tags remain |
| Master timeout | `master_mission_timeout` (1200 s) hard-aborts to terminal `MISSION_TIMED_OUT` |
| Delivery timeout | `delivery_timeout` (90 s) caps time spent in DELIVERING |
| Search fallback | Dispatches `START_SEARCH` with docked tag list |
| Completion detection  | `docked_tags == target_tags` → MISSION_COMPLETE |

**Known gap:** `self.exploration_completed` is declared in the coordinator
but never set to `True` in the current implementation, and no node emits
`EXPLORATION_COMPLETE` on `/mission_status`. The SEARCHING phase is therefore
only reachable via the exploration timeout above. FR-EXP-05 is reworded
against the timeout behaviour in the requirements document to reflect this.

---

### 2.6  Search Subsystem — `search_stations`

**Owner:** Shashwat

**Purpose:** When exploration is complete but tags remain un-serviced, navigate
to pre-computed zones and spin to scan for the missing tag.

**Algorithm:**

1. On `START_SEARCH`, compute absolute search zones from relative offsets
   anchored to the robot's start position.
2. For each zone:
   a. Snap the zone coordinate to the nearest free cell on the occupancy grid
      (within `max_safe_search_radius` = 0.6 m; reduced from 1.5 m to
      avoid snapping into far-away free space during mid-arena recovery).
   b. Navigate to the safe cell via Nav2 `NavigateToPose`.
   c. On arrival (within `arrival_tolerance` = 0.4 m), spin 360° (0.5 rad/s × 13 s).
   d. If a tag interrupt occurs during spin, abort search.
3. If all zones exhausted with no detection → publish `SEARCH_FAILED`.

**Parameters:**

| Parameter | Value | Unit  | Description |
|---|---|---|---|
| relative_search_offsets| [(-0.75,-0.3),(1.25,2.7)] | m | Offsets from start pose |
| max_safe_search_radius | 0.6 | m | Max snap distance for free cell|
| spin_velocity | 0.5 | rad/s | Rotation speed for scan |
| spin_duration | 13.0 | s | Duration (covers > 360°) |
| max_nav_retries | 3 | — | Nav2 retry limit per zone |
| arrival_tolerance | 0.4 | m | Distance to trigger spin |

---

## 3  Revision History

| Version | Date | Author | Changes |
|---|---|---|---|
| 1.0 | 2026-04-13 | Jeon | Initial baseline |

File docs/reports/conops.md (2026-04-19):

# CDE2310 — AY25/26 Warehouse Delivery Mission

# CONCEPT OF OPERATIONS (CONOPS)

## Deterministic Ping Pong Ball Launcher System

| Field | Value |
|---|---|
| Group | 7 |
| Document Version | 1.0 |
| Date | 14 Feb 2026 |
| Module | CDE2310 |
| Semester | AY25/26 Semester 2 |

Prepared in accordance with:
- G1 Engineering Design Principles (Jan 2026) — Steps 1 through 5
- NASA Systems Engineering Handbook — Appendix S: ConOps Annotated Outline

---

## 1.0 Introduction

This Concept of Operations (CONOPS) document describes the development of a deterministic ping pong ball launcher system for the CDE2310 AY25/26 Warehouse Delivery Mission. It follows the V-Model design process (Steps 1 through 5) as outlined in the G1 Engineering Design Principles lecture and is structured in accordance with the NASA Systems Engineering Handbook Appendix S ConOps annotated outline.

### 1.1 Project Description

#### 1.1.1 Background

The AY25/26 Warehouse Delivery Mission requires each team to design and build an autonomous or semi-autonomous system capable of delivering standard 40 mm ping pong balls to designated receptacle stations within a mock warehouse environment. The mission comprises two distinct delivery challenges:

- **Station A:** Deliver 3 balls to a stationary receptacle with specific timing intervals between each delivery (4-second gap after the first ball, 6-second gap after the second ball).
- **Station B:** Deliver balls to a moving receptacle mounted on a motorised linear rail, requiring the system to detect AprilTag ID 3 on the rail carriage and fire reactively.

The need for this system arises from the requirement to demonstrate competence in systematic engineering design, mechatronic integration, and deterministic control. The system must achieve reliable, repeatable ball delivery with gentle exit velocities in the range of 1–2 m/s.

#### 1.1.2 Assumptions and Constraints

- **A1:** The playing field dimensions, station positions, and receptacle geometries are as defined in the mission brief on the AY25-26 GitHub repository.
- **A2:** Standard 40 mm table-tennis balls (approximately 2.7 g) will be used.
- **C1:** All structural and mechanical components shall be manufacturable via FDM 3D printing with standard PLA/PETG filament.
- **C2:** Total system cost shall not exceed the allocated project budget.
- **C3:** The system shall comply with all safety regulations specified in the mission brief.
- **C4:** The launcher shall be powered entirely by the TurtleBot3 Burger's onboard Raspberry Pi 4B GPIO (no external Arduino or additional microcontroller).
- **C5:** The system footprint shall not exceed 235 × 230 × 300 mm to remain compatible with the TurtleBot3 base.

### 1.2 Overview of the Envisioned System

#### 1.2.1 System Overview

The envisioned system is a spring-loaded ball launcher mechanism mounted on a TurtleBot3 Burger (235 × 230 × 24.5 mm base). The launcher uses a rack-and-pinion plunger-and-barrel assembly actuated by an MG90 continuous-rotation servo to compress and release a spring, propelling balls with deterministic, repeatable force. A 7-ball gravity-fed tube feeds balls into the 42.5 mm inner-diameter barrel, and the RPi 4B running ROS 2 Humble sequences the launch timing and, for Station B, coordinates delivery with the moving receptacle via AprilTag vision (RPi Camera V2, tag36h11 family).

#### 1.2.2 System Scope

The project scope encompasses the mechanical launcher subsystem (barrel, plunger, spring mechanism), the ball-feed subsystem (gravity-fed tube), the control and actuation subsystem (RPi 4B, MG90 servo, RPi Camera V2), and the integration platform (TurtleBot3 Burger with 3D-printed mounts). The project does not encompass the warehouse field infrastructure, the receptacle stations themselves, or the motorised rail for Station B, as these are provided by the mission organisers.

---

## 2.0 Step 1 — Problem Definition & Requirements

Following the G1 design process, the first step is to rigorously define the problem before implementing any solution. This section establishes the Needs, Goals, and Objectives (NGOs), the system requirements, and the corresponding Measures of Performance (MOPs) and Technical Performance Measures (TPMs).

### 2.1 Needs, Goals, and Objectives

**Need:** A system that can reliably deliver ping pong balls to both stationary and moving receptacle stations in a simulated warehouse environment.

**Goal:** Achieve 100% delivery success rate at Station A and the highest feasible hit rate at Station B during the mission demo.

**Objectives:**
- Achieve a total launch cycle time of ≤ 0.87 seconds per ball.
- Maintain gentle exit velocity in the 1–2 m/s range.
- Operate within the TurtleBot3 Burger size/weight envelope (235 × 230 × ~300 mm total with payload).
- Require no human intervention once the mission begins.
- Complete all deliveries within the 25-minute mission window.

### 2.2 System Requirements

Requirements are written as unambiguous, singular, verifiable "shall" statements in accordance with good requirements practice (G1 lecture — Characteristics of Good Individual System Requirements).

| Req. ID | Requirement Statement | MOP/TPM | Verification |
|---|---|---|---|
| SYS-001 | The system shall deliver 3 balls to Station A within 15 seconds total cycle time (including 4 s and 6 s inter-delivery gaps). | Cycle time ≤ 15 s | Test |
| SYS-002 | The system shall achieve a ball exit velocity of 1–2 m/s (±0.2 m/s). | Measured velocity via high-speed video | Test |
| SYS-003 | The system shall deliver balls to Station B's moving receptacle with ≥ 67% hit rate (2 out of 3 balls). | Hit rate % | Test / Demo |
| SYS-004 | The system shall fit within a footprint of 235 × 230 × 300 mm (on TurtleBot3 base). | Measured dimensions | Inspection |
| SYS-005 | All 3D-printed components shall be manufacturable on a standard FDM printer with ≤ 0.3 mm tolerance compensation. | Dimensional accuracy | Inspection |
| SYS-006 | The launcher shall fire one ball per cycle in ≤ 0.87 seconds. | Time per cycle | Test |
| SYS-007 | The feed tube shall hold a minimum of 7 balls without manual reloading. | Ball capacity count | Inspection |
| SYS-008 | The system shall detect AprilTag ID 3 (tag36h11 family) on the Station B rail and fire reactively with a minimum 4-second cooldown between shots. | Detection latency, cooldown enforcement | Test |
| SYS-009 | The launcher shall be controlled entirely via RPi 4B GPIO (pin 12, 50 Hz PWM) without an external microcontroller. | Hardware inspection | Inspection |

*Table 1: System Requirements Matrix.*

### 2.3 Stakeholder Identification

| Stakeholder | Role | Expectations |
|---|---|---|
| NUS EDIC Panel (Module Instructors) | Mission authority, evaluation panel | Mission success rate, design rigour, adherence to V-model process, safety compliance |
| Group 7 Engineering Team | Designers, builders, and operators | Feasibility, integration risk, manageable schedule, clear work division |
| Jeon Won Je | Lead — final system integration, nav tuning, manufacturing | System-level coherence, reliable integration, clean nav behaviour |
| Shashwat Gupta | Mission coordinator, docking, perception | Reliable mission FSM, precise docking alignment, trustworthy AprilTag detection |
| Kuga | Navigation core | Robust autonomous exploration, accurate goal selection |
| Clara Ong | Delivery server, perception | Reliable delivery logic, reactive firing, AprilTag integration |
| Daniel Yow | Mechanical subsystem (CAD, manufacturing, mounts) | Manufacturable parts, clean mechanical-electrical interfaces |
| Mission Organisers | Field layout, scoring criteria, rail operation | Compliance with mission brief, fair assessment conditions |
| Future CDE2310 Cohorts | Potential re-users of design documentation | Documentation clarity, reproducibility of results |

---

## 3.0 Step 2 — Literature Review / Research

The literature review surveys existing technologies, prior art, and enabling innovations relevant to the launcher design problem. This research informs and constrains the concept generation in Step 3.

### 3.1 Ball Launching Mechanisms

A review of ball-launching mechanisms reveals several established approaches used in recreational, sporting, and educational robotics contexts:

- **Flywheel launchers:** Counter-rotating wheels grip and accelerate the ball. Advantages include continuous feed capability and adjustable speed via wheel RPM. Disadvantages include spin imparted to the ball, inconsistent grip on lightweight 2.7 g ping pong balls, and higher power draw.
- **Spring-loaded / plunger mechanisms:** A compressed spring stores potential energy and releases it to propel the ball through a barrel. Advantages include highly deterministic energy transfer, mechanical simplicity, and low power requirements (only the servo needs power). Disadvantages include single-shot per cycle and the need for a reliable cocking/reset mechanism.
- **Pneumatic launchers:** Compressed air propels the ball. Advantages include smooth acceleration and adjustable force. Disadvantages include the need for a pressure source (pump or pre-charged reservoir), sealing complexity, and difficulty achieving gentle exit velocities in the 1–2 m/s range.
- **Catapult / trebuchet mechanisms:** A lever arm stores energy via torsion spring or counterweight. Advantages include simplicity. Disadvantages include large form factor incompatible with the TurtleBot3 envelope and difficulty achieving repeatable, gentle trajectories.

### 3.2 Feed and Magazine Systems

Ball feed mechanisms reviewed include gravity-fed hoppers with agitator paddles, spring-loaded tube magazines, and rotary indexing drums. For this application (7 balls), a simple gravity-fed tube offers the best balance of reliability and simplicity. Balls drop one at a time into the barrel bore under gravity, ensuring consistent positioning before each shot.

### 3.3 Sensing and Tracking Technologies

For Station B (moving target), potential sensing approaches include:

- **Optical encoders or limit switches** on the motorised rail (if accessible) for position feedback — ruled out as the rail is provided infrastructure and not accessible for sensor mounting.
- **Time-of-flight (ToF) or ultrasonic distance sensors** to detect receptacle position — limited angular resolution and susceptible to reflections in a confined maze.
- **Computer vision with a camera module** for real-time tracking — selected approach. The RPi Camera V2 paired with AprilTag detection (tag36h11 family) provides 6-DOF pose estimation of tag ID 3 mounted on the rail carriage. Detection runs at camera frame rate and triggers reactive firing.
- **Pre-programmed timing** based on characterisation of the rail speed profile (open-loop) — considered as a fallback if vision proves unreliable in testing.

The team selected computer vision (RPi Camera V2 + AprilTag 36h11) as the primary sensing strategy for Station B, with pre-programmed timing as a fallback.

### 3.4 3D Printing and Manufacturability Considerations

Key findings from the literature and prior team experience with FDM printing include the importance of designing adequate clearance for sliding fits (typically 0.3–0.5 mm per side for PLA), accounting for FDM expansion by modelling parts 0.3 mm smaller than target dimensions, and using chamfers at barrel entries and plunger interfaces to prevent binding. Surface finish treatments such as light sanding of barrel interiors can also improve sliding performance — this was confirmed during prototyping when risk R1 (binding) materialised and was resolved by sanding the barrel interior combined with 0.3 mm tolerance compensation in CAD.

### 3.5 Applicable Standards and References

- AY25-26 Warehouse Delivery Mission Brief (GitHub Repository).
- NASA Systems Engineering Handbook, SP-2016-6105 Rev 2.
- G1 Engineering Design Principles lecture notes (Jan 2026).
- TurtleBot3 Burger technical specifications (ROBOTIS e-Manual).
- ROS 2 Humble Hawksbill documentation (docs.ros.org).
- AprilTag: A robust and flexible visual fiducial system — Olson, E. (2011), IEEE ICRA.
- MG90 Micro Servo datasheet (Tower Pro).

---

## 4.0 Step 3 — Concept(s) Design

Following the literature review, the team brainstorms and develops multiple candidate concepts for each subsystem. Each concept is described at a sufficient level of detail to allow comparative evaluation in the BOGAT stage (Step 4).

### 4.1 Concept A — Spring-Loaded Plunger Launcher

This concept uses a linear spring compressed by a servo-driven rack-and-pinion mechanism. The MG90 continuous-rotation servo (GPIO 12, 50 Hz PWM, duty cycle 10.0 for CCW) drives a pinion gear that advances a rack, compressing the spring against the plunger. Upon release, the plunger (40 mm shaft diameter) travels through a 42.5 mm inner-diameter barrel, propelling the 40 mm ball. Key features include:

- 40 mm diameter plunger shaft for centring within the barrel.
- 2.5 mm total clearance between ball and barrel wall (1.25 mm per side).
- Chamfered barrel entry to prevent ball jamming.
- Spring constant and compression distance selected to achieve 1–2 m/s exit velocity.
- Gravity-fed tube (7-ball capacity) drops one ball at a time into the barrel.
- Complete launch cycle time of 0.87 seconds per ball.

### 4.2 Concept B — Dual-Flywheel Launcher

This concept employs two counter-rotating DC motor-driven wheels. The ball is fed between the wheels via a guide channel. Wheel spacing is set to slightly compress the 40 mm ball for grip. Motor RPM is controlled to regulate exit velocity. A spring-loaded pusher feeds balls from a hopper into the wheel gap. Key concerns include:

- Spin imparted to the lightweight 2.7 g ball causes unpredictable trajectories.
- Inconsistent grip force on a thin-walled, deformable ping pong ball.
- Higher power draw from two DC motors.
- More complex speed control circuitry (ESC or H-bridge per motor).

### 4.3 Concept C — Pneumatic Piston Launcher

This concept uses a small air reservoir and solenoid valve to deliver a controlled air pulse behind the ball seated in the barrel. Pressure is regulated to achieve gentle exit velocity. Key concerns include:

- Requires a pressure source (pump or pre-charged reservoir), adding weight and volume.
- Sealing complexity for consistent pressure delivery.
- Difficulty achieving gentle 1–2 m/s exit velocity without overshooting or undershooting.
- Solenoid valve adds cost and electrical complexity.

### 4.4 Subsystem Concept Summary

| Subsystem | Concept A | Concept B | Concept C | Selected |
|---|---|---|---|---|
| Launcher | Spring plunger (rack-and-pinion servo release) | Dual flywheel (counter-rotating DC motors) | Pneumatic piston (solenoid + air reservoir) | Concept A |
| Feed System | Gravity-fed tube (7-ball) | Spring pusher + hopper | Manual load per shot | Concept A |
| Aiming | Fixed mount on TurtleBot3 + shim adjustment | Pan-tilt servo platform | Rail-mounted sliding bracket | Concept A |
| Sensing (Stn B) | Computer vision (RPi Camera V2 + AprilTag 36h11) | Time-of-flight sensor | Pre-programmed open-loop timing | Concept A (vision) |
| Control | RPi 4B + ROS 2 Humble + GPIO servo control | Arduino + ESC motor control | Arduino + solenoid driver | Concept A (RPi) |

*Table 2: Subsystem Concept Matrix.*

---

## 5.0 Step 4 — BOGAT (Bunch of Guys/Gals Around a Table)

The BOGAT stage is a structured cross-functional review where all team members evaluate the candidate concepts from Step 3. The purpose is to identify blind spots, surface trade-offs across disciplines (mechanical, electrical, software, manufacturing), and converge on the most promising concept for preliminary design.

### 5.1 Evaluation Criteria

The following weighted criteria were used to evaluate concepts. Criteria and weights were agreed upon by all team members before scoring to reduce bias:

| Criterion | Weight | Description |
|---|---|---|
| Determinism / Repeatability | 25% | How consistently can the concept deliver balls to the same spot under identical conditions? |
| Manufacturability | 20% | Ease of fabrication with FDM 3D printing; tolerance sensitivity; assembly complexity. |
| Mechanical Simplicity | 15% | Number of moving parts, failure modes, and maintenance needs. |
| Power / Energy | 10% | Power consumption, battery requirements, and energy efficiency. |
| Controllability (Station B) | 15% | Ease of integrating timing/tracking for the moving target scenario. |
| Cost | 10% | Estimated BOM cost within budget constraints. |
| Safety | 5% | Risk of injury during operation, testing, and transport. |

*Table 3: BOGAT Evaluation Criteria.*

### 5.2 Trade Study / Decision Matrix

Each concept is scored 1–5 against each criterion (5 = best). The weighted total determines the ranking.

| Criterion | Wt. | Concept A (Spring Plunger) | Concept B (Dual Flywheel) | Concept C (Pneumatic) |
|---|---|---|---|---|
| Determinism / Repeatability | 0.25 | 5 (1.25) | 3 (0.75) | 3 (0.75) |
| Manufacturability | 0.20 | 4 (0.80) | 3 (0.60) | 2 (0.40) |
| Mechanical Simplicity | 0.15 | 4 (0.60) | 2 (0.30) | 2 (0.30) |
| Power / Energy | 0.10 | 5 (0.50) | 2 (0.20) | 3 (0.30) |
| Controllability (Stn B) | 0.15 | 4 (0.60) | 4 (0.60) | 3 (0.45) |
| Cost | 0.10 | 5 (0.50) | 3 (0.30) | 2 (0.20) |
| Safety | 0.05 | 4 (0.20) | 3 (0.15) | 2 (0.10) |
| **WEIGHTED TOTAL** | **1.00** | **4.45** | **2.90** | **2.50** |

*Table 4: Decision Matrix.*

### 5.3 BOGAT Outcomes and Rationale

The team reviewed all three concepts with cross-disciplinary input from mechanical (Daniel), software/controls (Jeon, Shashwat, Kuga, Clara), and integration perspectives. Key discussion points included:

- **Determinism was the decisive factor.** The spring-plunger mechanism stores a fixed amount of energy (½kx²) and releases it identically each cycle. The flywheel concept's friction-dependent grip on a 2.7 g ball introduced unacceptable variability in exit velocity. The pneumatic concept's sealing tolerances made pressure consistency difficult to guarantee.
- **Manufacturability strongly favoured Concept A.** The barrel, plunger, and rack-and-pinion gears are straightforward FDM prints. The flywheel concept requires precise wheel spacing and balanced motors. The pneumatic concept requires airtight seals — difficult to achieve with FDM.
- **Power budget was a concern.** Concept A requires only a single MG90 servo (powered from RPi GPIO), whereas the flywheel needs two DC motors and ESCs, and the pneumatic needs a pump or pre-charged reservoir.
- **Shashwat raised the binding risk** for Concept A (3D-printed barrel/plunger fit). The team agreed to mitigate this with 0.3 mm FDM tolerance compensation and post-print sanding — a known, manageable risk.

Based on the trade study, the team selects **Concept A (Spring-Loaded Plunger Launcher)** for advancement to Preliminary Design. Key rationale:

1. Highest determinism and repeatability — critical for mission scoring.
2. Simplest mechanical design — fewest moving parts, lowest failure modes.
3. Lowest power consumption — single MG90 servo, no additional motor drivers.
4. Best manufacturability — all components are straightforward FDM prints with known tolerance compensation strategies.

---

## 6.0 Step 5 — Preliminary Design

The preliminary design elaborates the selected concept (Concept A — Spring-Loaded Plunger Launcher) into a detailed engineering definition suitable for review at the Preliminary Design Review (PDR).

### 6.1 System Architecture

The system is decomposed into the following major subsystems:

- **Launcher Subsystem:** A 42.5 mm inner-diameter barrel houses a 40 mm plunger shaft. A compressed spring is loaded via a rack-and-pinion mechanism driven by an MG90 continuous-rotation servo. The servo drives the pinion gear (CCW at duty cycle 10.0), which advances the rack to compress the spring. Upon full compression, the rack disengages and the spring propels the plunger forward, launching the ball. The spring constant and compression distance are tuned to yield 1–2 m/s exit velocity. Chamfered barrel entry prevents ball jamming. FDM tolerance compensation of 0.3 mm is applied to all sliding interfaces.

- **Ball Feed Subsystem:** A 7-ball gravity-fed tube sits above the barrel. Balls (40 mm diameter, ~2.7 g) drop into the barrel bore one at a time under gravity as each shot clears the chamber. Capacity of 7 balls provides 3 per station plus 1 spare.

- **Control Subsystem:** The Raspberry Pi 4B serves as the sole controller, running ROS 2 Humble. The consolidated `delivery_server` node drives the MG90 servo directly via GPIO pin 12 at 50 Hz PWM — no separate shooter node. For Station A, the delivery server executes a timed sequence (fire → 4 s wait → fire → 6 s wait → fire). For Station B, it subscribes to `/detections` (AprilTagDetectionArray), and upon detecting tag ID 3 within the pixel crosshair window, fires reactively with a 4-second cooldown between shots. The RPi Camera V2 feeds the team's `apriltag_docking` package, a composable vision container (camera → resize → rectify → `apriltag_ros::AprilTagNode`) that performs real-time tag36h11 detection and publishes 6-DOF pose as TF frames plus an `apriltag_msgs/AprilTagDetectionArray` on `/detections`.

- **Structural Platform:** The TurtleBot3 Burger (235 × 230 × 24.5 mm) serves as the base platform. 3D-printed mounts and guides secure the launcher assembly to the TurtleBot3's top plate. The total system height including the launcher and magazine is approximately 300 mm. Daniel's CAD assembly ensures all mechanical interfaces are dimensionally consistent and printable.

### 6.2 Key Design Parameters

| Parameter | Value | Justification / Traced Req. |
|---|---|---|
| Ball diameter | 40 mm | Standard table-tennis ball spec (A2). |
| Ball mass | ~2.7 g | Standard table-tennis ball spec (A2). |
| Barrel inner diameter | 42.5 mm | 2.5 mm total clearance to prevent jamming (SYS-005). |
| Plunger shaft diameter | 40 mm | Centring within barrel; 0.3 mm FDM compensation applied (SYS-005). |
| Servo model | MG90 continuous rotation | Low cost, sufficient torque for rack-and-pinion cocking. |
| Servo GPIO pin | 12 (BCM) | RPi 4B hardware PWM-capable pin (SYS-009). |
| PWM frequency | 50 Hz | Standard servo control frequency. |
| CCW duty cycle | 10.0 | Calibrated for consistent rack advance speed. |
| Time per launch cycle | 0.87 s | Measured; satisfies SYS-006. |
| Target exit velocity | 1–2 m/s | SYS-002; gentle delivery per mission brief. |
| Feed tube capacity | 7 balls | 3 per station + 1 spare (SYS-007). |
| FDM tolerance compensation | −0.3 mm | Modelled parts 0.3 mm undersized to account for FDM expansion (SYS-005). |
| System footprint | 235 × 230 × ~300 mm | On TurtleBot3 Burger base with launcher payload (SYS-004). |
| Station A inter-delivery gaps | 4 s, then 6 s | Per mission brief timing requirements (SYS-001). |
| Station B cooldown | 4.0 s | Minimum wait between reactive shots (SYS-008). |
| Station B target tag | AprilTag ID 3 (tag36h11) | Per mission brief; detected by RPi Camera V2 (SYS-008). |

*Table 5: Key Design Parameters.*

### 6.3 Operational Scenarios

#### 6.3.1 Nominal Operation — Station A (Stationary Target)

The mission coordinator sends `START_DELIVERY` with target `tag36h11:0` to the delivery server. The consolidated delivery server directly controls the MG90 servo via GPIO to fire the first ball, waits 4 seconds, fires the second ball, waits 6 seconds, then fires the third ball. Each fire cycle triggers the servo to rotate CCW (duty 10.0), launching one ball from the feed tube through the barrel. Upon completion of all 3 shots, the delivery server publishes `DELIVERY_COMPLETE` on `/mission_status`. Total Station A delivery time is approximately 14 seconds.

#### 6.3.2 Nominal Operation — Station B (Moving Target)

The mission coordinator sends `START_DELIVERY` with target `tag36h11:2` to the delivery server. The delivery server activates dynamic delivery mode and subscribes to `/detections` from the `apriltag_docking` vision container. The RPi Camera V2 continuously captures frames, which the detector processes for tag36h11 markers. When AprilTag ID 3 (mounted on the moving rail carriage) enters the camera's field of view and its center pixel falls within ±50 px of the crosshair (x = 320), the delivery server fires directly via GPIO and enters a 4-second cooldown period. During cooldown, further detections are ignored. After cooldown expires, the system is ready for the next reactive shot. This repeats for up to 3 shots. Upon firing 3 balls or upon mission coordinator timeout, `DELIVERY_COMPLETE` is published.

#### 6.3.3 Off-Nominal / Failure Scenarios

- **Ball jam in barrel (R1):** Plunger binds due to FDM tolerance issues. Mitigated by 0.3 mm tolerance compensation in CAD and post-print sanding of barrel interior. During testing, this risk materialised and was successfully resolved with these mitigations.
- **Feed tube jam:** Ball fails to drop into barrel. Mitigated by gravity-fed design with sufficient tube clearance.
- **Sensor failure — Station B (R3):** Camera feed drops or AprilTag detection fails. Fallback: pre-programmed timing mode based on characterised rail speed profile (open-loop). During development, the team confirmed AprilTag vision was reliable and did not need to deploy the fallback.
- **Spring fatigue (R2):** Spring provides inconsistent force after repeated cycles. Mitigated by selecting a quality spring, characterising fatigue behaviour in testing, and carrying a spare spring in the kit.
- **Servo stall / overload:** MG90 servo stalls during rack-and-pinion cocking. The consolidated delivery server enforces a threading lock to prevent concurrent fire commands and a `max_dynamic_shots = 3` counter to prevent over-cycling.

---

## 6.4 Preliminary Design Validation

Prior to PDR, the team validated the preliminary design against the system requirements (Table 1) through the following methods:

- **Analytical calculation** of spring energy and exit velocity vs. SYS-002: ½kx² energy budget confirmed to yield 1–2 m/s for the selected spring constant and compression distance, given the 2.7 g ball mass.
- **CAD interference and tolerance stack-up analysis** vs. SYS-004 and SYS-005: Daniel's CAD assembly verified all parts fit within the 235 × 230 × 300 mm envelope with no interferences.
- **Prototype barrel/plunger fit check** via test prints: Initial prints confirmed binding risk (R1). After applying 0.3 mm tolerance compensation and sanding barrel interiors, smooth sliding fit was achieved.
- **Functional firing test:** Measured launch cycle time of 0.87 seconds per ball (SYS-006) and exit velocity in the 1–2 m/s range (SYS-002) using high-speed video analysis.
- **AprilTag detection validation:** Confirmed reliable detection of tag36h11 ID 3 at Station B operating distances using the RPi Camera V2 and the `apriltag_docking` composable vision pipeline (resize → rectify → `apriltag_ros::AprilTagNode`).

---

## 7.0 Risks and Potential Issues

| ID | Risk Description | Likelihood | Impact | Mitigation Strategy | Status |
|---|---|---|---|---|---|
| R1 | 3D-printed parts bind due to insufficient clearance between plunger (40 mm) and barrel (42.5 mm ID). | Medium | High | Design with 0.3 mm FDM compensation; test-print fit checks early; sand barrel interior post-print. | Realised and resolved — sanding + tolerance compensation eliminated binding. |
| R2 | Spring provides inconsistent force over repeated launch cycles due to fatigue. | Low | High | Select quality spring; characterise fatigue behaviour over 50+ cycles; carry spare spring in kit. | Monitored — no degradation observed in testing. |
| R3 | Moving target tracking (Station B) proves unreliable with reactive vision approach. | Medium | Medium | Primary: AprilTag vision (RPi Camera V2 + tag36h11 ID 3). Fallback: pre-programmed open-loop timing based on rail speed characterisation. | Resolved — AprilTag vision selected and validated; open-loop fallback available but not needed. |
| R4 | Budget overrun due to component sourcing delays for servo, spring, or camera module. | Low | Medium | Identify alternative suppliers; order critical items (MG90 servo, RPi Camera V2) early in project timeline. | Mitigated — all components sourced on schedule. |
| R5 | Gravity-fed tube fails to reliably drop balls into barrel bore. | Low | Medium | Gravity-fed design minimises moving parts; test with actual 40 mm ping pong balls early; adjust tube clearances if needed. | Monitored — reliable in testing with 7-ball loads. |

*Table 6: Risk Register.*

---

## 8.0 Summary and Path Forward

This CONOPS document has outlined the problem definition, system requirements, literature review findings, candidate concepts, BOGAT trade-study evaluation, and preliminary design for the CDE2310 Warehouse Delivery Mission ping pong ball launcher system. The selected concept — **Concept A (Spring-Loaded Plunger Launcher)** — provides the best balance of deterministic performance, manufacturability, and controllability as validated through the weighted decision matrix (score: 4.45/5.00, versus 2.90 for dual flywheel and 2.50 for pneumatic).

The system integrates a rack-and-pinion servo-driven spring release, a 7-ball gravity-fed tube, and RPi Camera V2 AprilTag vision — all controlled by the Raspberry Pi 4B running ROS 2 Humble — mounted on the TurtleBot3 Burger platform within a 235 × 230 × ~300 mm footprint.

**Immediate next steps:**
1. Complete the preliminary design documentation and prepare for the 20-minute Preliminary Design Review (PDR) presentation.
2. Upon PDR approval, proceed to the build/prototype phase (Step 6: Prototyping and Testing) per the V-Model design process.
3. Fabricate all 3D-printed components with validated 0.3 mm tolerance compensation.
4. Integrate launcher assembly onto TurtleBot3 and perform end-to-end firing tests at both Station A and Station B configurations.
5. Conduct full mission rehearsals within the 25-minute window to validate system-level performance.

**Team responsibilities for next phase:**

| Member | Responsibility |
|---|---|
| Jeon Won Je | Final system integration, nav tuning, manufacturing (lead) |
| Shashwat Gupta | Mission coordinator, docking server, perception integration |
| Kuga | Navigation core — exploration, frontier search, goal selection |
| Clara Ong | Delivery server, perception (`apriltag_docking`) |
| Daniel Yow | Mechanical subsystem — CAD finalisation, 3D printing, hardware docs |

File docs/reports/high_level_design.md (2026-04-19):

# High-Level Design

| Field | Value |
|---|---|
| Document ID | AMR-HLD-001 |
| Version | 1.0 |
| Date | 2026-04-13 |
| Author(s) | Group 7 — Jeon, Shashwat, Kuga, Clara, Daniel |
| Module | CDE2310 Engineering Systems Design |
| Status | Baselined for G2 |

---

## 1  Purpose

This document describes the top-level architecture of the Group 7 AMR system.
It decomposes the system into packages, maps software to hardware, and defines
the data-flow and interface topology that links every component.

---

## 2  Architectural Overview

The system follows a **two-machine distributed ROS 2** architecture. Compute-
heavy navigation and planning run on a laptop, while hardware-coupled perception
and actuation run on the Raspberry Pi mounted to the robot.

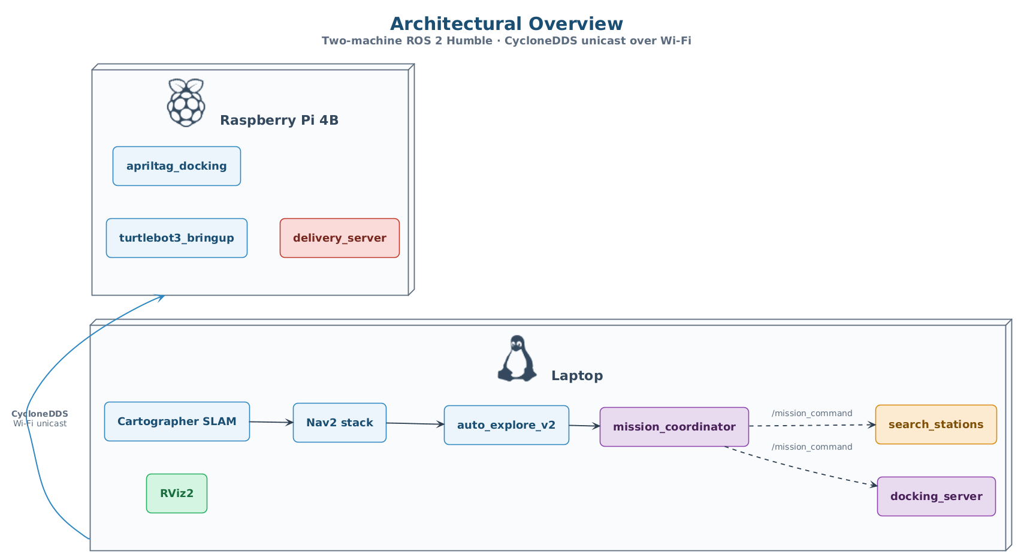
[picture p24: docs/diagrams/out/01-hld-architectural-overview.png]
Figure 1 — Architectural Overview


*Figure 1 — Two-machine ROS 2 Humble architecture over CycloneDDS. Source: [`../diagrams/01-hld-architectural-overview.puml`](../diagrams/01-hld-architectural-overview.puml).*

---

## 3  Package Decomposition

### 3.1  Package Map

```
src/
├── auto_explore_v2/            # Frontier exploration (Nav2 stack)
│   ├── find_frontiers.py       #   BFS frontier detection + clustering
│   └── score_and_post.py       #   Frontier scoring + Nav2 goal posting
│
└── CDE2310_AMR_Trial_Run/      # Mission-level coordination
    ├── mission_coordinator_v3.py  # Central FSM
    ├── docker.py               #   Geometric visual-servoing docking
    ├── delivery_server_consolidated.py  # Static/dynamic delivery orchestration
    └── search_stations.py      #   Zone-based tag search fallback
```

### 3.2  Package Responsibility Matrix

| Package | Responsibility | Machine | Depends on |
|---|---|---|---|
| `auto_explore_v2` | BFS frontiers, scored Nav2 goals | Laptop  | Nav2, Cartographer |
| `CDE2310_AMR_Trial_Run` | Central FSM, docking, delivery, search | Laptop + RPi | Nav2, TF2, auto_explore_v2 |

---

## 4  Data Flow

### 4.1  Primary Data Flow (Exploration → Detection → Delivery)

Figure 2 — Primary Data Flow

*Figure 2 — Exploration, detection and delivery data chain across the laptop / RPi split. Source: [`../diagrams/02-hld-data-flow.puml`](../diagrams/02-hld-data-flow.puml).*

### 4.2  Command / Status Bus

All coordination flows through two JSON-encoded String topics:

```
 ┌──────────────────┐          /mission_command          ┌──────────────────┐
 │  mission_        │ ──────────────────────────────────► │  docker.py       │
 │  coordinator_v3  │ ──────────────────────────────────► │  delivery_server │
 │                  │ ──────────────────────────────────► │  search_stations │
 └────────▲─────────┘                                    └──────┬───────────┘
          │                                                     │
          │              /mission_status                        │
          └─────────────────────────────────────────────────────┘

 Command format:  {"action": "START_DOCKING", "target": "tag36h11:0", ...}
 Status format:   {"sender": "docker", "status": "DOCKING_COMPLETE", "data": "tag36h11:0"}
```

---

## 5  Interface Summary

### 5.1  ROS 2 Topics (Key)

| Topic | Type | Publisher(s) | Subscriber(s) |
|---|---|---|---|
| `/map` | OccupancyGrid | Cartographer | find_frontiers, search_stations |
| `/scan` | LaserScan | LDS-02 driver | Cartographer, Nav2 |
| `/cmd_vel` | Twist | Nav2, docker | OpenCR (motor driver) |
| `/camera/image_raw`  | Image | `camera_ros::CameraNode` (RPi)  | `image_proc::ResizeNode` (inside apriltag_docking container) |
| `/mission_command` | String (JSON) | mission_coordinator | docker, delivery_server, searcher |
| `/mission_status` | String (JSON) | docker, deliverer, searcher, score_and_post | mission_coordinator |
| `/goal_pose` | PoseStamped | score_and_post | Nav2 planner |
| `/detections` | AprilTagDetectionArray | `apriltag_ros::AprilTagNode` (inside apriltag_docking container, RPi) | delivery_server, mission_coordinator |
| `/detected_dock_pose_{0,2}` | PoseStamped | `apriltag_docking::detected_dock_pose_publisher_{0,2}` (RPi) | docker |
| `frontiers` | String (JSON) | find_frontiers | score_and_post |

### 5.2  ROS 2 Services

| Service | Type | Server | Client |
|---|---|---|---|
| `toggle_exploration` | SetBool | score_and_post | mission_coordinator |
| `clear_blacklist` | Empty | score_and_post | mission_coordinator |

### 5.3  ROS 2 Actions

| Action | Type | Server  | Client |
|---|---|---|---|
| `navigate_to_pose` | NavigateToPose | Nav2 | score_and_post, docker, search |
| `compute_path_to_pose` | ComputePathToPose | Nav2 | score_and_post |

---

## 6  Hardware-Software Mapping

Figure 3 — Hardware-Software Mapping

*Figure 3 — TurtleBot3 Burger (MeowthBot) layer stack. Source: [`../diagrams/03-hld-hardware-software-mapping.puml`](../diagrams/03-hld-hardware-software-mapping.puml).*

---

## 7  Technology Stack

| Layer | Technology |
|---|---|
| OS | Ubuntu 22.04 (RPi + Laptop) |
| Middleware | ROS 2 Humble + CycloneDDS (FastRTPS for Gazebo/WSL2) |
| SLAM | Cartographer (google_cartographer_ros) |
| Navigation | Nav2 (planner, controller, behaviours, BT) |
| Perception | `apriltag_docking` composable container (wraps upstream `apriltag_ros`, `image_proc`, `camera_ros`) |
| Build system  | colcon + ament_python |
| Language | Python 3.10 |
| Version ctrl  | Git + GitHub |
| Camera driver | v4l2_camera (RPi Camera V2 via CSI) |

---

## 8  Design Decisions

| ID | Decision | Rationale |
|---|---|---|
| DD-01 | Two-machine split (RPi + laptop) | RPi lacks compute for Nav2 + SLAM; laptop cannot access GPIO. |
| DD-02 | JSON-encoded String topics for command/status bus | Avoids custom message definitions; fast iteration. |
| DD-03 | Discrete geometric docking instead of PID | Eliminates gain-tuning; state machine is more debuggable. |
| DD-04 | BFS frontier detection (not RRT or information-gain) | Simpler to implement and debug; sufficient for maze. |
| DD-05 | Tag blacklisting on dock failure | Prevents infinite retry loops on bad-angle detections. |
| DD-06 | `apriltag_docking` composable pipeline (wrapping upstream `apriltag_ros`) over a team-written Python detector | Zero-copy camera→detect path on the RPi; per-station `nav2_dock_target_{id}` frames + `detected_dock_pose_publisher` give Nav2-consumable PoseStamped without reinventing pose estimation. |

---

## 9  Revision History

| Version | Date | Author | Changes |
|---|---|---|---|
| 1.0 | 2026-04-13 | Jeon | Initial baseline |

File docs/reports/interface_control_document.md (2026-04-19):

# Interface Control Document

| Field | Value |
|---|---|
| Document ID | AMR-ICD-001 |
| Version | 1.0 |
| Date | 2026-04-13 |
| Author(s) | Group 7 — Jeon, Shashwat, Kuga, Clara, Daniel |
| Module | CDE2310 Engineering Systems Design |
| Status | Baselined for G2 |

---

## 1  Purpose

This Interface Control Document (ICD) formally specifies every software, hardware,
and network interface in the Group 7 AMR system. It serves as the single source of
truth for node interconnections and is used during integration testing to verify
that all interfaces are correctly wired.

---

## 2  ROS 2 Topic Interfaces

### 2.1  Sensor Topics

| # | Topic | Message Type | Publisher | Subscriber(s) | QoS Profile | Machine |
|---|---|---|---|---|---|---|
| 1 | `/scan` | `sensor_msgs/LaserScan` | LDS-02 driver | Cartographer, Nav2 costmap | Best-effort, volatile | RPi |
| 2 | `/camera/image_raw` | `sensor_msgs/Image` | `camera_ros::CameraNode` (1640×1232 BGR888 @ 10 Hz, inside `apriltag_vision_container`) | `image_proc::ResizeNode` (same container) | Best-effort, volatile | RPi |
| 3 | `/camera/camera_info` | `sensor_msgs/CameraInfo` | `camera_ros::CameraNode` | `image_proc::ResizeNode` | Best-effort, volatile | RPi |
| 4 | `/imu` | `sensor_msgs/Imu` | OpenCR | Cartographer | Best-effort, volatile | RPi |
| 5 | `/odom` | `nav_msgs/Odometry` | OpenCR (diff-drive) | Cartographer, Nav2 | Best-effort, volatile | RPi |

### 2.2  Map & Navigation Topics

| # | Topic | Message Type | Publisher | Subscriber(s) | QoS Profile | Machine |
|---|---|---|---|---|---|---|
| 6 | `/map` | `nav_msgs/OccupancyGrid` | Cartographer | find_frontiers, score_and_post, search_stations, Nav2 costmap | Reliable, transient local | Laptop  |
| 7 | `/goal_pose` | `geometry_msgs/PoseStamped` | score_and_post | Nav2 bt_navigator | Reliable, volatile | Laptop  |
| 8 | `/cmd_vel` | `geometry_msgs/Twist` | Nav2 controller / docking_server / search_stations | OpenCR | Reliable, volatile | Both |

### 2.3  Perception Topics (all originate inside `apriltag_vision_container` on RPi)

| # | Topic | Message Type | Publisher | Subscriber(s) | QoS Profile | Machine |
|---|---|---|---|---|---|---|
| 9 | `/camera/resized/image_raw` | `sensor_msgs/Image` | `image_proc::ResizeNode` | `image_proc::RectifyNode` | Best-effort, volatile | RPi |
| 10| `/camera/resized/camera_info` | `sensor_msgs/CameraInfo` | `image_proc::ResizeNode` | `image_proc::RectifyNode`, `apriltag_ros::AprilTagNode` | Best-effort, volatile | RPi |
| 11| `/camera/resized/image_rect` | `sensor_msgs/Image` | `image_proc::RectifyNode` | `apriltag_ros::AprilTagNode` | Best-effort, volatile | RPi |
| 12| `/detections` | `apriltag_msgs/AprilTagDetectionArray`| `apriltag_ros::AprilTagNode` | delivery_server, mission_coordinator | Best-effort, volatile | RPi |
| 13| `/detected_dock_pose_0` | `geometry_msgs/PoseStamped` (frame_id = `camera`) | `apriltag_docking::detected_dock_pose_publisher_0` (10 Hz) | docker | Reliable, volatile | RPi |
| 14| `/detected_dock_pose_2` | `geometry_msgs/PoseStamped` (frame_id = `camera`) | `apriltag_docking::detected_dock_pose_publisher_2` (10 Hz) | docker | Reliable, volatile | RPi |
| 15| `/tf` | `tf2_msgs/TFMessage` (`camera → tag36h11:{0,2}`) | `apriltag_ros::AprilTagNode` (dynamic); four static broadcasters (`base_link→camera_link`, `camera_link→camera`, `tag36h11:0→nav2_dock_target_0`, `tag36h11:2→nav2_dock_target_2`) | mission_coordinator, docker | Reliable, volatile | RPi |

### 2.4  Mission Coordination Topics

| # | Topic | Message Type | Publisher | Subscriber(s) | QoS Profile | Machine |
|---|---|---|---|---|---|---|
| 16| `/mission_command` | `std_msgs/String` (JSON) | mission_coordinator | docker, delivery_server, search_stations | Reliable, volatile | Laptop  |
| 17| `/mission_status` | `std_msgs/String` (JSON) | docker (`sender: docker`), delivery_server (`sender: deliverer`), search_stations (`sender: searcher`) | mission_coordinator | Reliable, volatile | Both |

### 2.5  Exploration-Internal Topics

| # | Topic | Message Type | Publisher | Subscriber(s) | QoS Profile | Machine |
|---|---|---|---|---|---|---|
| 18| `frontiers` | `std_msgs/String` (JSON) | find_frontiers | score_and_post | Reliable, volatile | Laptop  |
| 19| `bfs_distance_transform` | `std_msgs/String` (JSON) | find_frontiers | score_and_post | Reliable, volatile | Laptop  |
| 20| `/nav_status` | `std_msgs/String` | score_and_post | find_frontiers | Best-effort, volatile | Laptop  |

---

## 3  Mission Command Protocol

All commands are JSON-encoded `std_msgs/String` messages on `/mission_command`.

### 3.1  Command Schema

```json
{
  "action": "<ACTION_NAME>",
  "target": "<tag_name or null>",
  "<extra_key>": "<extra_value>"
}
```

### 3.2  Command Catalogue

| Action | Target | Extra Fields | Issued By | Consumed By |
|---|---|---|---|---|
| `START_DOCKING` | `tag36h11:<id>` | — | mission_coordinator  | docker |
| `START_UNDOCKING` | — | — | mission_coordinator  | docker |
| `START_DELIVERY`  | `tag36h11:<id>` | — | mission_coordinator  | delivery_server  |
| `START_SEARCH` | `tag36h11:<id>` | `docked_tags: [...]` | mission_coordinator  | search_stations  |
| `ABORT_SEARCH` | — | — | mission_coordinator  | search_stations  |

### 3.3  Status Schema

```json
{
  "sender": "<node_name>",
  "status": "<STATUS_CODE>",
  "data": "<tag_name or detail string>"
}
```

### 3.4  Status Catalogue

| Sender | Status | Data | Meaning |
|---|---|---|---|
| `docker` | `DOCKING_COMPLETE` | `tag36h11:<id>` | Robot docked at tag |
| `docker` | `DOCKING_FAILED` | `tag36h11:<id>` | Docking aborted (timeout/geometry) |
| `docker` | `UNDOCKING_COMPLETE` | — | Robot cleared from tag |
| `deliverer` | `BALL_FIRED` | shot detail | Single ball confirmed fired |
| `deliverer` | `DELIVERY_COMPLETE` | `tag36h11:<id>` | All balls delivered at station |
| `searcher` | `SEARCH_FAILED` | — | All search zones exhausted, no tag |

**Note:** `EXPLORATION_COMPLETE` is defined in the contract but is **not currently emitted** by any node. The mission coordinator reaches SEARCHING via its `initial_exploration_timeout` instead (see Subsystem Design §2.5 "Known gap").

---

## 4  ROS 2 Service Interfaces

| # | Service | Type | Server | Client(s) | Machine |
|---|---|---|---|---|---|
| 1 | `toggle_exploration` | `std_srvs/SetBool` | score_and_post | mission_coordinator | Laptop  |
| 2 | `clear_blacklist` | `std_srvs/Empty` | score_and_post | mission_coordinator | Laptop  |

### 4.1  Service Details

**toggle_exploration (SetBool):**
- `request.data = true` → resume frontier exploration.
- `request.data = false` → pause (cancel active Nav2 goal, stop posting new goals).
- `response.success` always `true`; `response.message` confirms the toggle state.

**clear_blacklist (Empty):**
Clears the frontier penalty blacklist accumulated by `score_and_post`. Called by
the mission coordinator after successful dock/delivery cycles so penalised
frontiers become eligible again.

**delivery_server (consolidated):**
The delivery_server directly controls the MG90 servo via GPIO 12 on the RPi.
It handles both shot orchestration and hardware control — there is no separate
shooter node or `/fire_ball` service.

---

## 5  ROS 2 Action Interfaces

| # | Action | Type | Server | Client(s) | Machine |
|---|---|---|---|---|---|
| 1 | `navigate_to_pose` | `nav2_msgs/NavigateToPose` | Nav2 | score_and_post, docker, search | Laptop  |
| 2 | `compute_path_to_pose`  | `nav2_msgs/ComputePathToPose` | Nav2 | score_and_post | Laptop  |

### 5.1  Action Details

**navigate_to_pose:**
- Goal: `PoseStamped` in `map` frame.
- Feedback: current pose during navigation.
- Result: success/failure status code.
- Used by exploration (scored goals), docking (staging waypoint), and search
  (zone navigation).

**compute_path_to_pose:**
- Goal: `PoseStamped` in `map` frame.
- Result: `nav_msgs/Path` — used by `score_and_post` for pre-flight validation
  before committing to a frontier goal.

---

## 6  TF Tree

Figure 7 — TF Tree

*Figure 7 — Live TF tree from `ros2 run tf2_tools view_frames`. Source: [`../diagrams/07-icd-tf-tree.puml`](../diagrams/07-icd-tf-tree.puml).*

**Note:** tag36h11 ID 3 is consumed from `/detections` by the delivery server for
Station B reactive fires and is **not** broadcast as a TF frame.

**Publishers:**
- `map → odom`: Cartographer (SLAM correction).
- `odom → base_footprint → base_link`: OpenCR odometry.
- `base_link → base_scan`: LiDAR driver (TurtleBot3 bringup).
- `base_link → camera_link`: static transform publisher (apriltag_docking launch, x=0.09 y=0.05 z=0.097).
- `camera_link → camera`: static transform publisher (optical-frame rotation, yaw=-π/2 roll=-π/2).
- `camera → tag36h11:{0,2}`: `apriltag_ros::AprilTagNode` (dynamic, per-frame).
- `tag36h11:{0,2} → nav2_dock_target_{0,2}`: static transform publishers (apriltag_docking launch, x=0.195 z=0.05 pitch=-π/2 roll=π/2).

**Stale TF policy:** The mission coordinator considers a tag transform stale if
its timestamp is older than 0.5 s relative to `now()`. Stale transforms are
ignored to prevent acting on "ghost" detections.

---

## 7  Hardware Interfaces

### 7.1  GPIO / PWM (RPi 4B)

| Pin | Function | Connected To | Protocol |
|---|---|---|---|
| GPIO 12 | PWM output | MG90 servo (launcher) | Hardware PWM |
| GND | Common ground | Servo, motor, OpenCR 5 V regulator | — |

### 7.2  Serial / USB

| Interface | Protocol | Endpoints | Baud Rate |
|---|---|---|---|
| USB | Serial | RPi USB ↔ OpenCR | 115200 |

The OpenCR board communicates with the RPi via USB serial. The
`turtlebot3_bringup` node handles this transparently.

### 7.3  Camera

| Interface | Protocol | Endpoints |
|---|---|---|
| CSI | MIPI CSI-2 | RPi Camera V2 → RPi CSI port |

The `v4l2_camera` ROS 2 node exposes the camera as `/camera/image_raw`.

### 7.4  LiDAR

| Interface | Protocol | Endpoints |
|---|---|---|
| USB | Serial | LDS-02 → OpenCR → RPi (via USB) |

The LDS-02 LiDAR publishes 360° scans at ~5 Hz on the `/scan` topic.

---

## 8  Network Interfaces

### 8.1  DDS Configuration

| Parameter | Value |
|---|---|
| DDS (real robot) | CycloneDDS (`rmw_cyclonedds_cpp`) |
| DDS (Gazebo sim, WSL2) | FastRTPS (`rmw_fastrtps_cpp`) — CycloneDDS fails under Gazebo/WSL2|
| Discovery | Unicast peer list (no multicast) |
| Discovery config | `CYCLONEDDS_URI` → XML with explicit peer IP addresses |
| ROS_DOMAIN_ID | Gazebo forces `0`; real robot per operator env (not set in launch)|

**CycloneDDS XML profile** (set via `CYCLONEDDS_URI`):
- Disables multicast discovery.
- Adds peer IP addresses for unicast initial-peers list.
- Required on both machines for cross-machine topic discovery under WSL2 mirrored networking.

### 8.2  Environment Variables (Both Machines)

```bash
# Real robot (RPi + remote PC)
export RMW_IMPLEMENTATION=rmw_cyclonedds_cpp
export CYCLONEDDS_URI=file:///path/to/cyclonedds.xml

# Gazebo sim on WSL2 (overrides the above)
export RMW_IMPLEMENTATION=rmw_fastrtps_cpp
```

### 8.3  Time Synchronisation

| Parameter | Value |
|---|---|
| Method | Manual offset (no NTP between machines)  |
| Measured offset | ~0.40 s (RPi ahead of laptop) |
| Mitigation | Stale TF threshold (0.5 s) absorbs drift |
| use_sim_time | `false` (real hardware) |

---

## 9  Interface Verification Checklist

| # | Interface | Verification Method | Pass? |
|---|---|---|---|
| 1 | `/scan` RPi → Laptop | `ros2 topic hz /scan` on laptop | ☐ |
| 2 | `/camera/image_raw` on RPi | `ros2 topic echo /camera/image_raw --once` | ☐ |
| 3 | `/map` published by Cartographer | Visualise in RViz | ☐ |
| 4 | `/cmd_vel` reaches OpenCR | Send manual Twist, observe wheel motion | ☐ |
| 5 | `toggle_exploration` service | `ros2 service call` SetBool | ☐ |
| 6 | delivery_server servo on RPi | Start delivery_server, verify GPIO 12 servo fires | ☐ |
| 7 | TF: `camera_link → tag36h11:0` | Hold tag in front of camera, check `tf2_echo`| ☐ |
| 8 | `/mission_command` propagation | Publish test JSON, verify subscriber logs | ☐ |
| 9 | DDS cross-machine discovery | `ros2 node list` on both machines | ☐ |

---

## 10  Revision History

| Version | Date | Author | Changes |
|---|---|---|---|
| 1.0 | 2026-04-13 | Jeon | Initial baseline |

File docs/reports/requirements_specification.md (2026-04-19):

# Requirements Specification

| Field | Value |
|---|---|
| Document ID | AMR-RS-001 |
| Version | 1.0 |
| Date | 2026-04-13 |
| Author(s) | Group 7 — Jeon, Shashwat, Kuga, Clara, Daniel |
| Module | CDE2310 Engineering Systems Design |
| Status | Baselined for G2 |

---

## 1  Purpose

This document defines the functional, non-functional, and constraint requirements
for the Group 7 Autonomous Mobile Robot (AMR). Every requirement is traceable to
the Concept of Operations (ConOps) and informs the verification plan in the
Testing Documentation.

---

## 2  Scope

The AMR shall autonomously explore a closed maze environment, detect AprilTag
delivery stations, dock at each station, and deliver ping-pong balls within a
single 25-minute mission window. The robot platform is a TurtleBot3 Burger with
a custom spring-loaded launcher payload.

---

## 3  Definitions & Abbreviations

| Term | Definition |
|---|---|
| AMR | Autonomous Mobile Robot |
| AprilTag | Fiducial marker system (family tag36h11) |
| Nav2 | ROS 2 Navigation Stack |
| SLAM | Simultaneous Localisation and Mapping |
| FSM | Finite State Machine |
| DDS | Data Distribution Service (ROS 2 middleware) |
| FAT | Factory Acceptance Test |
| ConOps | Concept of Operations |
| RPi | Raspberry Pi 4B |
| LiDAR | Light Detection and Ranging (LDS-02 on TurtleBot3)  |

---

## 4  Functional Requirements

### 4.1  Exploration

| ID | Requirement | Traces to |
|---|---|---|
| FR-EXP-01 | The AMR shall build an occupancy grid map of the maze using Cartographer SLAM. | ConOps §5.3 |
| FR-EXP-02 | The AMR shall detect frontier cells (boundary between explored free space and unknown space) via BFS flood-fill. | ConOps §5.3 |
| FR-EXP-03 | The AMR shall cluster frontiers and score them by a weighted combination of BFS distance and cluster size. | ConOps §5.3 |
| FR-EXP-04 | The AMR shall autonomously navigate to the highest-scored frontier goal until no frontiers remain. | ConOps §5.3 |
| FR-EXP-05 | The mission coordinator shall transition EXPLORING → SEARCHING when the `initial_exploration_timeout` (480 s) expires while un-serviced target tags remain. | ConOps §5.3 |

### 4.2  Detection

| ID | Requirement | Traces to |
|---|---|---|
| FR-DET-01 | The AMR shall detect tag36h11 AprilTag markers via the `apriltag_docking` composable vision pipeline (camera → resize → rectify → detect) running on the RPi Camera V2. | ConOps §5.4 |
| FR-DET-02 | The `apriltag_docking` package shall compute and publish the 6-DOF pose of each detected marker as TF frames (`camera → tag36h11:{0,2}`) and as `geometry_msgs/PoseStamped` on `/detected_dock_pose_{0,2}` for Nav2-consumable docking servoing, plus an `AprilTagDetectionArray` on `/detections`. | ConOps §5.4 |
| FR-DET-03 | The mission coordinator shall monitor the TF tree for target tags (`tag36h11:0`, `tag36h11:2`) with a staleness threshold of 0.5 s. | ConOps §5.4 |

### 4.3  Docking

| ID | Requirement | Traces to |
|---|---|---|
| FR-DCK-01 | The AMR shall navigate to a staging point 0.40 m in front of the detected tag using Nav2 NavigateToPose. | ConOps §5.5 |
| FR-DCK-02 | The AMR shall execute a discrete geometric visual-servoing sequence (intercept → square-up → final plunge) to dock within 0.10 m of the tag. | ConOps §5.5 |
| FR-DCK-03 | If docking fails, the coordinator shall blacklist the tag for 30 s and resume exploration. | ConOps §5.5 |
| FR-DCK-04 | The docking server shall abort if the total docking time exceeds 180 s. | ConOps §5.5 |

### 4.4  Delivery

| ID | Requirement | Traces to |
|---|---|---|
| FR-DEL-01 | At a **static station** (tag36h11:0), the AMR shall fire 3 balls in a timed sequence (fire → 4 s wait → fire → 6 s wait → fire). | ConOps §5.6 |
| FR-DEL-02 | At a **dynamic station** (tag36h11:2), the AMR shall detect the passing target (tag ID 3), fire on detection, and repeat up to 3 shots with a 4 s cooldown. | ConOps §5.6 |
| FR-DEL-03 | The delivery_server shall directly control the MG90 servo via GPIO 12 to activate the launcher mechanism. | ConOps §5.6 |

### 4.5  Mission Coordination

| ID | Requirement | Traces to |
|---|---|---|
| FR-MSN-01 | A central FSM shall orchestrate exploration, docking, delivery, undocking, and search phases. | ConOps §5.2 |
| FR-MSN-02 | The FSM shall transition to SEARCHING when exploration is complete but un-serviced tags remain. | ConOps §5.7 |
| FR-MSN-03 | The FSM shall report MISSION_COMPLETE when all target tags have been serviced. | ConOps §5.8 |

---

## 5  Non-Functional Requirements

| ID | Category | Requirement |
|---|---|---|
| NFR-01 | Timing | The full mission shall complete within 25 minutes. |
| NFR-02 | Timing | Tag detection latency shall not exceed 100 ms per frame at 10 Hz. |
| NFR-03 | Accuracy | Docking lateral error (Y-offset) shall be ≤ 0.03 m at final stop. |
| NFR-04 | Accuracy | Docking yaw error shall be ≤ 0.05 rad (≈ 3°) at final stop. |
| NFR-05 | Reliability | The system shall tolerate camera dropout for up to 1.0 s during docking without aborting. |
| NFR-06 | Reliability | The system shall handle Nav2 goal rejection by applying a fallback staging offset (−0.15 m). |
| NFR-07 | Power | The RPi and launcher shall operate from the TurtleBot3 11.1 V LiPo battery via the OpenCR 5 V regulator for the full mission duration. |
| NFR-08 | Comms | DDS discovery between RPi and laptop shall use CycloneDDS with unicast peers (no multicast). FastRTPS is used only as a Gazebo/WSL2 fallback (issue #19). |

---

## 6  Constraints

| ID | Constraint |
|---|---|
| CON-01 | Mission duration: 25 minutes maximum. |
| CON-02 | Maze dimensions: provided by NUS EDIC at competition time; walls ≥ 0.3 m high.|
| CON-03 | Delivery payload: 7 ping-pong balls (3 per station + 1 spare). |
| CON-04 | Platform: TurtleBot3 Burger (ROBOTIS); no structural modification to base. |
| CON-05 | Software: ROS 2 Humble on Ubuntu 22.04 (RPi and laptop). |
| CON-06 | Communication: Wi-Fi link between RPi and laptop; no tethered connection. |
| CON-07 | Autonomy: no manual teleoperation after mission start. |

---

## 7  Requirement Traceability Matrix

| Req ID | ConOps §  | Design § | Test § |
|---|---|---|---|
| FR-EXP-01  | 5.3 | HLD §3.1 | TST-INT-01 |
| FR-EXP-02  | 5.3 | SSD §2.1 | TST-UT-01 |
| FR-EXP-03  | 5.3 | SSD §2.1 | TST-UT-01 |
| FR-DET-01  | 5.4 | SSD §2.2 | TST-INT-02 |
| FR-DET-02  | 5.4 | SSD §2.2 | TST-INT-02 |
| FR-DCK-01  | 5.5 | SSD §2.3 | TST-SYS-01 |
| FR-DCK-02  | 5.5 | SSD §2.3 | TST-SYS-01 |
| FR-DEL-01  | 5.6 | SSD §2.4 | TST-SYS-02 |
| FR-DEL-02  | 5.6 | SSD §2.4 | TST-SYS-02 |
| FR-MSN-01  | 5.2 | SSD §2.5 | TST-SYS-03 |
| FR-MSN-02  | 5.7 | SSD §2.5 | TST-SYS-03 |

---

## 8  Revision History

| Version | Date | Author | Changes |
|---|---|---|---|
| 1.0 | 2026-04-13 | Jeon | Initial baseline |

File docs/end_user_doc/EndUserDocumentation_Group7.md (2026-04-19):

# End User Documentation

## MeowthBot AMR

*Group 7 Engineering Company Pte Ltd*

<p align="center">
  Robot assembly — side view
  Robot assembly — front view
</p>

*Figure 1: Robot assembly — side view (left) and front view (right).*

---

## 1. General System Description & Critical Data

**Model:** TurtleBot3 Burger (MeowthBot) — Group 7 custom payload stack.

MeowthBot is an autonomous mobile robot that maps an unknown maze using
LiDAR-based SLAM, identifies two delivery stations via AprilTag markers, docks
geometrically on each, and launches ping-pong balls with a rack-and-pinion
plunger. A ROS 2 finite-state machine coordinates explore → detect → dock →
deliver → resume, spanning a Raspberry Pi 4 on-board computer and a remote
laptop over Wi-Fi (CycloneDDS).

### 1.1 Specification sheet

| Specification | Value |
|---|---|
| Platform | TurtleBot3 Burger (MeowthBot) |
| Dimensions (base) | 235 × 230 × 24.5 mm; ~300 mm total height with payload |
| Weight | 1300 g base / 1319 g with payload |
| Power / Battery | LB-012, 11.1 V 1800 mAh LiPo (nominal run ~80 min; ~26 min under full load) |
| Drive | Differential, 2× Dynamixel **XL430-W210** |
| Max linear velocity | 0.22 m/s (configurable) |
| LiDAR | LDS-02, 360° scan, 0.12–3.5 m |
| Onboard computer | Raspberry Pi 4 |
| Motor controller | OpenCR 1.0 (9-axis IMU) |
| Camera | Raspberry Pi Camera Module V2 (CSI), 640×480 rectified @ 10 Hz |
| Station marker | AprilTag 36h11, size **0.0986 m**, IDs 0 & 2 (dock tags), ID 3 (dynamic target) |
| Launcher | MG90 continuous-rotation servo + rack-and-pinion plunger with clutch-bearing reset |
| Launcher actuator | GPIO 12 (BCM), 50 Hz PWM, `CCW_DUTY = 10.0` (fire), `CW_DUTY = 5.0` (reset) |
| Launch cycle | 0.87 s per revolution |
| Ball capacity | **7 × 40 mm** ping-pong balls (3 Station A + 3 Station B + 1 spare) |
| DDS | CycloneDDS unicast, `ROS_DOMAIN_ID=0` |
| Mission budget | 25 min wall clock; master timeout 1200 s |

### 1.2 Operation summary

1. **Explore** — Frontier-based exploration over the `/map` occupancy grid. `find_frontiers` posts clusters; `score_and_post` scores them (size + BFS distance − penalties), preflights paths with `compute_path_to_pose`, and drives Nav2.
2. **Detect** — The mission coordinator polls the TF tree at 10 Hz for `tag36h11:0` (Station A) and `tag36h11:2` (Station B), published by `apriltag_docking`. A stale-TF threshold of 0.5 s filters camera flicker.
3. **Dock** — Stage at **0.40 m** via Nav2, then run COMPUTE_GEOMETRY → INTERCEPT → SQUARE_UP → EVALUATE_POSITION → (RETRY_BACKUP) → FINAL_PLUNGE to **0.10 m**.
4. **Deliver** — Coordinator publishes `{"action":"START_DELIVERY","target":"tag36h11:<N>"}` on `/mission_command`. Station A: 3 timed shots (4 s, 6 s gaps). Station B: reactive — fires when `tag36h11:3` crosses pixel x = 320 ± 50 px; 4 s cooldown; 3 shots max.
5. **Resume** — Undock, clear blacklist, resume exploration. If exploration has timed out (default 480 s) and tags remain, enter SEARCH over pre-computed offsets.

Figure 2: Mission flow activity diagram.

*Figure 2: Mission flow — system block flow diagram.*

### 1.3 Safety call-outs

- **Keep fingers clear** of launcher barrel and rack-and-pinion during operation. Rubber-band-driven plunger has pinch hazard during reset.
- **LiPo safety** — do not puncture, short-circuit, or discharge below 9 V; store in fireproof bag.
- **Robot moves without warning** once exploration starts. Maintain a clear 1 m perimeter.
- **LDS-02** emits Class 1 laser light; do not stare into the aperture.
- **Emergency stop** — press the OpenCR reset button to kill all motor output immediately.

---

## 2. Technical Guide

### 2.1 Packages

| Package | Machine | Purpose | Key nodes |
|---|---|---|---|
| `auto_explore_v2` | Laptop | Frontier exploration + Nav2 goal posting | `find_frontiers`, `score_and_post` |
| `CDE2310_AMR_Trial_Run` | Laptop | Mission FSM + docking + search | `mission_coordinator`, `docking_server`, `search_server` |
| `apriltag_docking` (C++) | RPi | Camera pipeline + tag detection + dock-pose publisher | `camera_ros` → `image_proc::Resize` → `image_proc::Rectify` → `apriltag_ros::AprilTagNode` → `detected_dock_pose_publisher` (×2) |
| `CDE2310_AMR_Trial_Run` (delivery) | RPi | MG90 servo driver + shot orchestration | `delivery_server` (imports `RPi.GPIO`) |

### 2.2 Deployment — 2 terminals

Pre-flight: 7 balls loaded in the feed tube; OpenCR powered, RPi booted (~30 s); both machines on the same Wi-Fi SSID; `ROS_DOMAIN_ID=0` and `RMW_IMPLEMENTATION=rmw_cyclonedds_cpp` set on both.

**Terminal 1 — RPi** (SSH in: `ssh ubuntu@<ROBOT_IP>`)
```
export TURTLEBOT3_MODEL=burger
ros2 launch turtlebot3_bringup robot.launch.py &
ros2 launch apriltag_docking apriltag_dock_pose_publisher.launch.py &
ros2 run CDE2310_AMR_Trial_Run delivery_server
```

**Terminal 2 — Laptop**
```
ros2 launch CDE2310_AMR_Trial_Run full_mission.launch.py
```

`full_mission.launch.py` starts Cartographer (SLAM), Nav2, RViz, `auto_explore_v2`, and the mission stack (`mission_coordinator` + `docking_server` + `search_server`) after a 15 s timer delay. The robot then explores, docks, and delivers autonomously.

### 2.3 Mission command / status contract

- **Topic:** `/mission_command`, type `std_msgs/String`, payload JSON.
  - Delivery: `{"action":"START_DELIVERY","target":"tag36h11:0"}` (or `:2`).
  - Docking: `{"action":"START_DOCKING","target":"nav2_dock_target_0"}` (or `_2`).
- **Topic:** `/mission_status`, type `std_msgs/String`, payload JSON. Senders emit `"docker"`, `"searcher"`, `"deliverer"`.

### 2.4 Key tunable parameters

| Parameter | Value | File |
|---|---|---|
| `staging_distance` | 0.40 m | `docker.py:73` |
| `stop_distance` | 0.10 m | `docker.py:74` |
| `max_docking_time` | 180 s | `docker.py:78` |
| `max_allowed_y_error` | 0.40 m | `docker.py:99` |
| `master_mission_timeout` | 1200 s | `mission_coordinator_v3.py:43` |
| `initial_exploration_timeout` | 480 s | `mission_coordinator_v3.py:44` |
| `delivery_timeout` | 90 s | `mission_coordinator_v3.py:45` |
| `stale_tf_threshold` | 0.5 s | `mission_coordinator_v3.py:54` |
| `crosshair_center_x / fire_window_tolerance` | 320 / 50 px | `delivery_server_consolidated.py:32-36` |
| `cooldown_seconds` | 4.0 s | `delivery_server_consolidated.py:46` |
| Tag size | 0.0986 m | `apriltag_docking/config/apriltags_36h11.yaml:5` |

### 2.5 Shutdown

`Ctrl+C` both terminals → switch off OpenCR → disconnect LiPo if storing >24 h.

---

## 3. Acceptable Defect Log

Defects below are mission-acceptable: the system has been verified to complete a
full 25 min run despite them. None constitute a safety hazard.

| # | Defect | Justification / containment |
|---|---|---|
| 1 | Feed-tube indexing occasionally hesitates after the 5th/6th ball (gravity-fed jam near end of stack). | Mission needs at most 6 balls fired; 1 spare is carried. If it stalls, the reset lever at the top of the feed tube can be bumped by hand during pre-run; does not affect runtime after first shot. (Issue #8, Open.) |
| 2 | Camera flicker under rapidly changing overhead lighting produces single-frame false tag detections. | Stale-TF threshold of 0.5 s in `mission_coordinator_v3.py` filters transient frames before a dock is commanded. No false docks observed in 10 runs. (Issue #5, Mitigated.) |
| 3 | Nav2 occasionally rejects staging goals near the map boundary. | `docker.py` subtracts `fallback_staging_offset = 0.15 m` and retries once; the 0.40 m stage target normally falls inside traversable space. (Issue #6, Mitigated.) |
| 4 | RPi–laptop clock drift up to ~0.4 s (no NTP configured between them). | Stale-TF threshold absorbs typical drift; TF ages within mission are always <1 s. (Issue #7, Open.) |
| 5 | Launcher rubber-band force decays ~3 % per 30 firings. | Range margin at launch is designed with >15 % headroom. Rubber band is replaced every lab session regardless. |
| 6 | Minor surface roughness inside 3D-printed launcher barrel; faint layer lines on mounts. | Plunger slides freely (sanded + silicone-lubed); structural loads are below 3DP yield envelope. No functional impact. |

---

## 4. Factory Acceptance Test (FAT)

Executed once before each mission run. All rows must pass to proceed.

| # | Check | Pass criterion | ☐ |
|---|---|---|---|
| 1 | LiPo pack voltage at rest | ≥ 11.4 V on multimeter (discard <10.8 V) | ☐ |
| 2 | OpenCR bringup (Terminal 1, RPi) | `ros2 topic list` shows `/scan`, `/odom`, `/cmd_vel`; no red errors in `turtlebot3_bringup` log | ☐ |
| 3 | LiDAR scan sanity | `ros2 topic echo /scan --once` returns a full 360° range array; no all-inf readings | ☐ |
| 4 | Camera frame publishing | `ros2 topic hz /camera/image_raw` ≈ 10 Hz | ☐ |
| 5 | AprilTag detection (static bench test) | With a 0.0986 m tag-ID-0 print at 1 m, `ros2 run tf2_ros tf2_echo camera tag36h11:0` shows a fresh transform (age <0.5 s) | ☐ |
| 6 | Dock-pose publisher | `ros2 topic echo /detected_dock_pose_0 --once` returns a PoseStamped with reasonable translation (~1 m x) | ☐ |
| 7 | Nav2 path planning | In RViz, set a test goal → Nav2 returns a plan within 5 s; robot follows without oscillating into walls | ☐ |
| 8 | Nav2 goal rejection recovery | Send a goal outside the mapped area → `docker.py` retries once with fallback offset, then aborts cleanly (no node crash) | ☐ |
| 9 | Delivery fire via `/mission_command` | Publish `{"action":"START_DELIVERY","target":"tag36h11:0"}` on `/mission_command` → servo fires 3 shots at 4 s / 6 s / 4 s intervals; all balls exit barrel | ☐ |
| 10 | Dynamic delivery targeting | Publish `{"action":"START_DELIVERY","target":"tag36h11:2"}` → servo fires when tag 3 crosses pixel x ≈ 320; ≥ 1 successful shot on a rail pass | ☐ |
| 11 | Full mission dry run | Explore → detect → dock → deliver at both stations within 25 min, no manual intervention post-start | ☐ |

---

## 5. Maintenance and Part Replacement Log

Cadences below are conservative and assume roughly one full mission run plus
two short bench tests per session. The detailed CAD version lineage (Launcher
v1.0.0 → v2.2.0) is in `hardware/README.md` — do not duplicate here.

### 5.1 Routine maintenance

| Part | Replacement trigger | Cadence | Notes | Ref |
|---|---|---|---|---|
| Launcher rubber band | Visible stretch set or range drop >15 % | Every lab session, or ~30 firings | Replace with same wall-thickness band; pre-stretch under the plunger to preload | `hardware/README.md` §Rubber band vs Spring |
| MG90 continuous servo | Audible jitter at `CCW_DUTY = 10.0`; reduced torque during rack load; stall during reset | On symptom | Test in isolation via `delivery_server` STATIC sequence; swap as a unit (horn included) | `hardware/README.md` §Launcher System |
| Clutch bearing | Inconsistent pinion reset position (plunger not fully forward) | On symptom | Degrease + re-grease with light bearing grease; replace if slip-direction fails | `hardware/README.md` §Clutch bearing reset |
| Rack–pinion gear pair | Skipped teeth under load, inconsistent engagement | On symptom | Verify washer stack between rack and plunger face; inspect for 3DP tooth wear | `hardware/README.md` §Rack and pinion engagement |
| LiPo pack (LB-012) | >150 cycles, or any cell imbalance >0.05 V, or any puffing | Cycle-tracked | Log every charge; store at 3.8 V/cell if >1 week unused | §1.3 Safety call-outs |
| Standoff screws / M3 hardware | Any self-loosening between layers (visual check) | Pre-mission | Keep ≥3 standoffs per layer engaged; spare M3×8, M3×12 in kit | `hardware/README.md` §Materials and Components |
| Camera CSI ribbon | Intermittent `/camera/image_raw` dropout | On symptom | Reseat at both RPi and camera ends; replace if crimped | — |
| 3D-printed launcher barrel | Visible cracking, plunger binding | On symptom | Re-print from `hardware/cad/launcher_v2.2.0/` | `hardware/README.md` §Final Performance summary |

### 5.2 Replacement log (fill during operation)

| Date | Part replaced | Reason / symptom | By | Ref photo / ticket |
|---|---|---|---|---|
| | | | | |
| | | | | |
| | | | | |
| | | | | |
| | | | | |

---

*Group 7 Engineering Company Pte Ltd*
*Document Version 2.1 — 2026-04-19 · 5 pages max — for Final Mission submission.*
*This document must remain with the robot at all times.*
*Robot Serial: Group 7, CDE2310 AY25/26, NUS EDIC.*

*v2.1 supersedes the printed v2.0 (2026-04-16): perception package corrected to `apriltag_docking`, drive actuator to XL430-W210, docking staging distance to 0.40 m, docking FSM expanded to the 8-state `docker.py` machine, launcher FAT updated to publish on `/mission_command` (the non-existent `/fire_ball` service was removed from §4), exploration-timeout default corrected to 480 s. Regenerate the printed PDF from this file before submission.*

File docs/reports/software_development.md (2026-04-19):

# Software Development Plan

| Field | Value |
|---|---|
| Document ID | AMR-SDP-001 |
| Version | 1.0 |
| Date | 2026-04-13 |
| Author(s) | Group 7 — Jeon, Shashwat, Kuga, Clara, Daniel |
| Module | CDE2310 Engineering Systems Design |
| Status | Baselined for G2 |

---

## 1  Purpose

This document specifies the development environment, build toolchain, repository
structure, branching strategy, coding standards, and dependency management for
the Group 7 AMR project.

---

## 2  Development Environment

| Component | Version / Detail |
|---|---|
| OS (laptop) | Ubuntu 22.04 LTS (Jammy Jellyfish) |
| OS (RPi) | Ubuntu 22.04 Server (arm64) |
| ROS distro | ROS 2 Humble Hawksbill |
| Python | 3.10.x (system Python, no virtual env for ROS) |
| DDS middleware  | CycloneDDS (`rmw_cyclonedds_cpp`); FastRTPS (`rmw_fastrtps_cpp`) only for Gazebo on WSL2 |
| Build system | colcon (v0.15+) |
| Package format | ament_python |
| IDE | VS Code with ROS extension + Python extension |
| Linter | flake8, pep257 |
| Formatter | (not enforced project-wide; flake8 for compliance) |

### 2.1  ROS 2 Workspace Setup

```bash
# Clone
mkdir -p ~/amr_ws/src && cd ~/amr_ws/src
git clone git@github.com:<org>/Group7_AMR.git .

# Install dependencies
cd ~/amr_ws
rosdep install --from-paths src --ignore-src -r -y

# Build
colcon build --symlink-install

# Source
source install/setup.bash
```

### 2.2  RPi Cross-Compilation (Not Used)

All RPi packages are built natively on the RPi. Cross-compilation was evaluated
and rejected due to complexity with camera and GPIO dependencies.

---

## 3  Repository Structure

```
Group7_AMR/
├── src/
│   ├── auto_explore_v2/           # Frontier exploration (Nav2)
│   │   ├── auto_explore_v2/
│   │   │   ├── __init__.py
│   │   │   ├── find_frontiers.py
│   │   │   └── score_and_post.py
│   │   ├── config/
│   │   │   └── nav2_params.yaml
│   │   ├── launch/
│   │   │   └── auto_explore.launch.py
│   │   ├── test/
│   │   │   ├── test_copyright.py
│   │   │   ├── test_flake8.py
│   │   │   └── test_pep257.py
│   │   ├── setup.py
│   │   └── package.xml
│   │
│   ├── CDE2310_AMR_Trial_Run/     # Mission coordination
│   │   ├── CDE2310_AMR_Trial_Run/
│   │   │   ├── __init__.py
│   │   │   ├── mission_coordinator_v3.py
│   │   │   ├── docker.py
│   │   │   ├── delivery_server_consolidated.py
│   │   │   └── search_stations.py
│   │   ├── config/
│   │   │   ├── slam_params.yaml
│   │   │   └── minimal_nav2.yaml
│   │   ├── launch/
│   │   │   ├── mission.launch.py
│   │   │   ├── full_mission.launch.py
│   │   │   └── minimal_nav2.launch.py
│   │   ├── test/
│   │   │   ├── test_copyright.py
│   │   │   ├── test_flake8.py
│   │   │   └── test_pep257.py
│   │   ├── setup.py
│   │   └── package.xml
│   │
│   └── apriltag_docking/          # C++ perception pipeline on RPi
│       ├── src/
│       │   └── detected_dock_pose_publisher.cpp
│       ├── include/
│       ├── launch/
│       │   └── apriltag_dock_pose_publisher.launch.py
│       ├── config/
│       │   └── apriltags_36h11.yaml
│       ├── CMakeLists.txt
│       └── package.xml
│
├── hardware/
│   ├── chassis/                   # TurtleBot3 assembly + mounts
│   │   ├── assembly/
│   │   ├── mounts/
│   │   └── 3mf/
│   └── launcher/                  # Launcher mechanism
│       ├── components/
│       ├── 3mf/
│       └── v1/
│
├── docs/
│   ├── reports/                   # Systems engineering documents
│   └── guides/                    # Developer guides
│
├── data/                          # Maps, bag files, logs
├── CHANGELOG.md
├── CLAUDE.md
├── AGENT_GIT_GUIDE.md
└── README.md
```

---

## 4  Branch Policy & Git Workflow

### 4.1  Branch Structure

```
main                      ← stable releases only
  │
  ├── dev/jeon            ← Jeon's development branch (lead)
  ├── dev/shashwat        ← Shashwat's development branch
  ├── dev/kuga            ← Kuga's development branch
  ├── dev/clara           ← Clara's development branch
  └── dev/daniel          ← Daniel's development branch
```

### 4.2  Rules

| Rule | Detail |
|---|---|
| No direct pushes to `main` | All changes via PR from `dev/*` branches |
| One feature per branch | If a dev branch is cluttered, create a topic branch |
| Build must pass before merge | `colcon build` + `colcon test` green |
| PR requires at least 1 review | Any team member may review |
| Squash merge preferred | Keeps `main` history clean |

### 4.3  Commit Conventions

We follow [Conventional Commits](https://www.conventionalcommits.org/):

```
<type>(<scope>): <short description>

[optional body]

[optional footer(s)]
```

**Types:**

| Type | Usage |
|---|---|
| `feat` | New feature |
| `fix` | Bug fix |
| `refactor` | Code restructuring (no behaviour change)  |
| `test` | Adding or updating tests |
| `docs` | Documentation only |
| `chore` | Build, CI, tooling changes |
| `perf` | Performance improvement |

**Scopes:** `nav`, `explore`, `dock`, `delivery`, `perception`, `launcher`,
`mission`, `hardware`, `report`

**Examples:**
```
feat(dock): add fallback staging offset on Nav2 rejection
fix(delivery): prevent double-fire during cooldown window
docs(report): add G2 systems design documentation
refactor(nav): consolidate scaffold packages into CDE2310_AMR_Trial_Run + auto_explore_v2
chore(bringup): add Gazebo maze world and mission sim launch
```

---
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

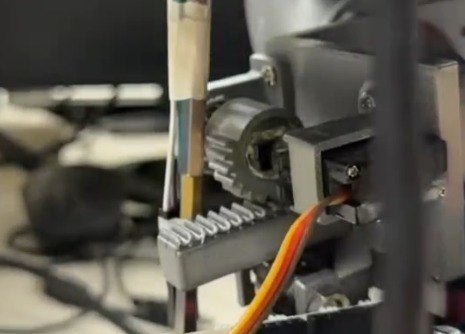
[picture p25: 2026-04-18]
hardware/docs/launcher_v2.2.0_irl_view_2.jpg

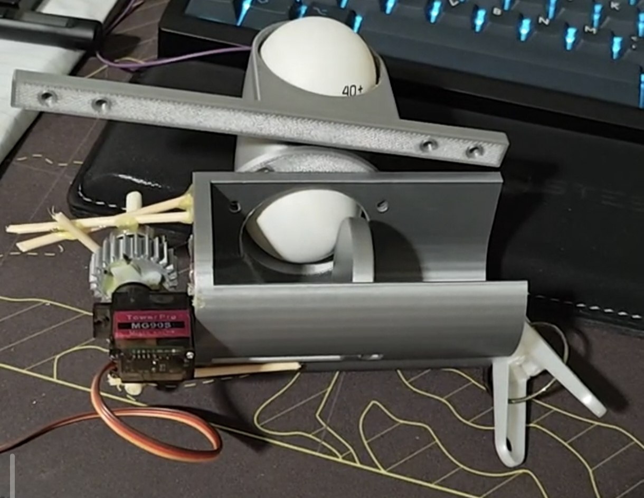
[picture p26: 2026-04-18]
hardware/docs/launcher_v2.1.0_irl_view_1.jpg

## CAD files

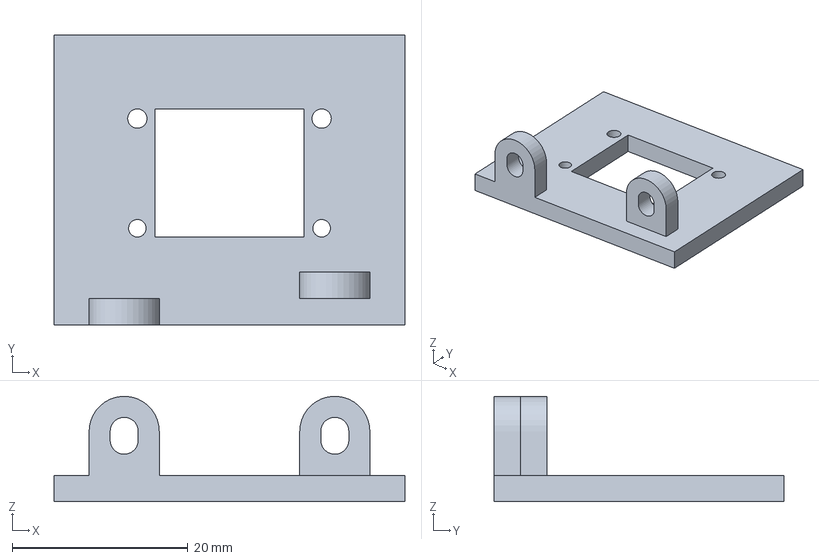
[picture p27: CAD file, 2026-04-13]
hardware/chassis/3mf/RPI camera mount.3mf
40.0 x 33.0 x 12.0 mm

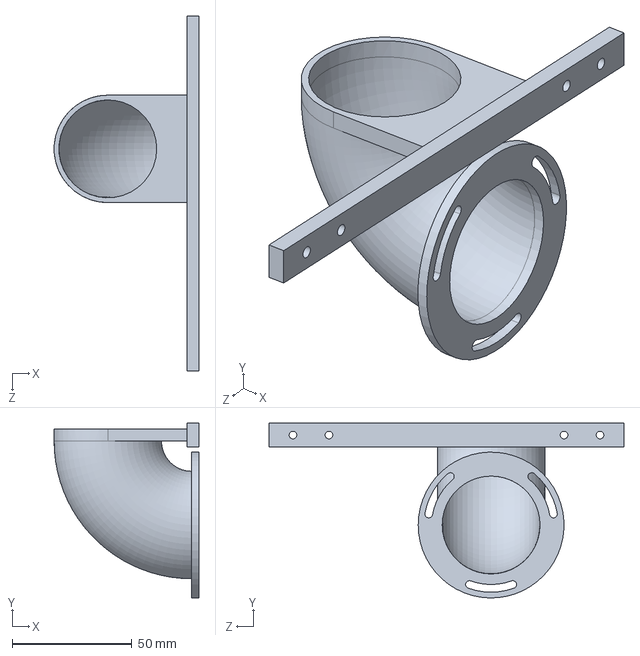
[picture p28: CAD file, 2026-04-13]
hardware/chassis/mounts/launcher mount v2.SLDPRT
60.4 x 72.9 x 148.0 mm

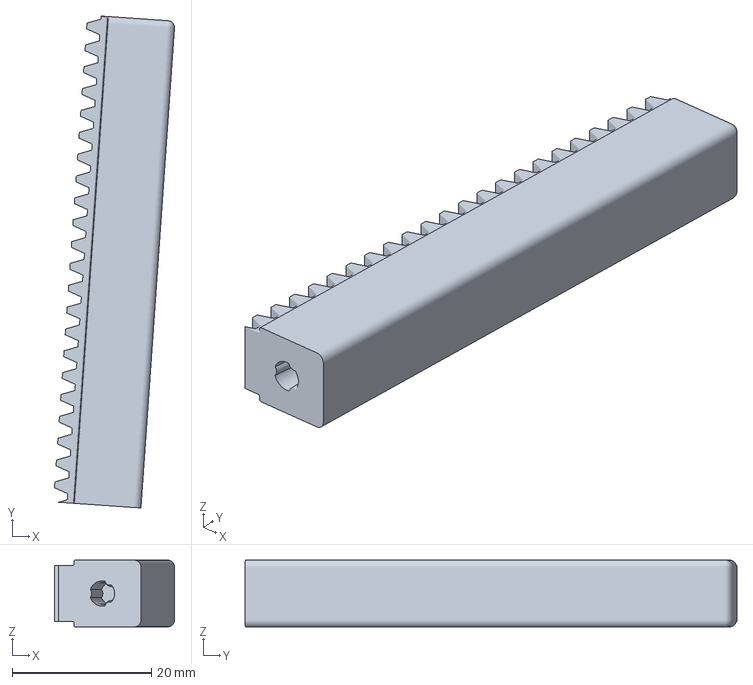
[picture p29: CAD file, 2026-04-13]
hardware/launcher/3mf/Plunger rack.3mf
17.2 x 70.6 x 9.60 mm

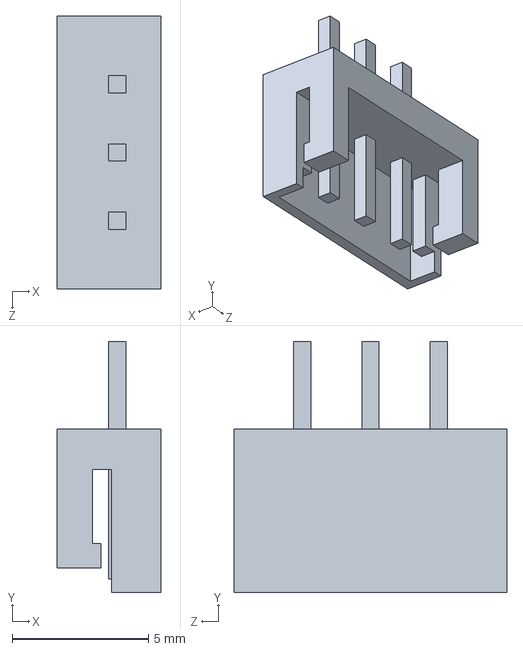
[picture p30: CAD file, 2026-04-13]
hardware/launcher/components/Part 3.SLDPRT
3.80 x 9.20 x 10.00 mm

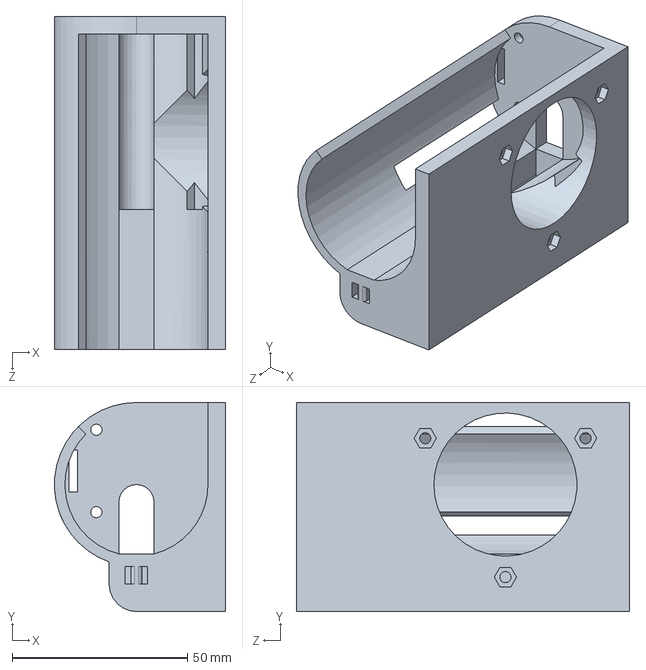
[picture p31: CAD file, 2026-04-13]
hardware/launcher/v1/launcher assembly/Tube.SLDPRT
48.8 x 59.6 x 95.0 mm

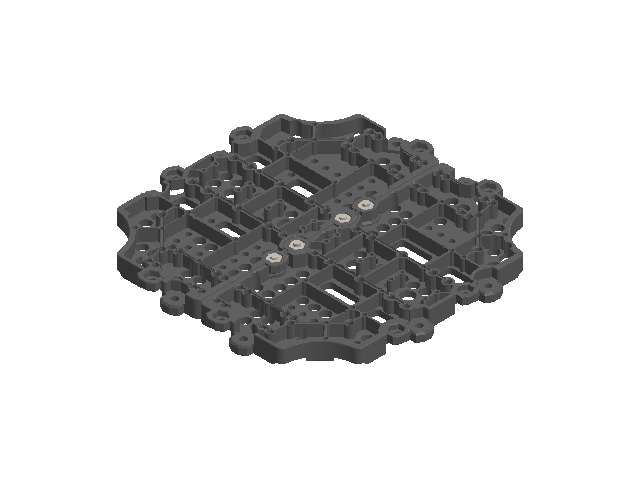
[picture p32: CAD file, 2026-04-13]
hardware/chassis/assembly/Waffle Layer.SLDASM
Waffle Plate x 2
pan cross head_ks x 4
hexagon nut style 1 gradeab_ks x 4

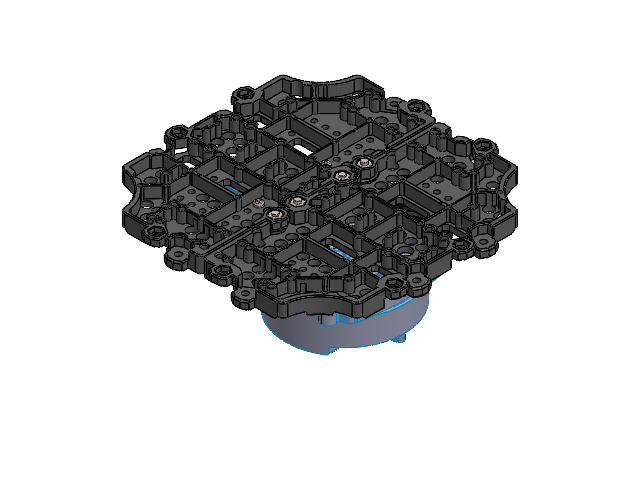
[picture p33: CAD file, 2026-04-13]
hardware/chassis/assembly/Fourth Layer.SLDASM
Waffle Plate x 2
pan cross head_ks x 12
hexagon nut style 1 gradeab_ks x 8
PR30_IBB_01_3D x 4
M_PR07_A01_SPACER_RIVET x 4
LDS Dummy

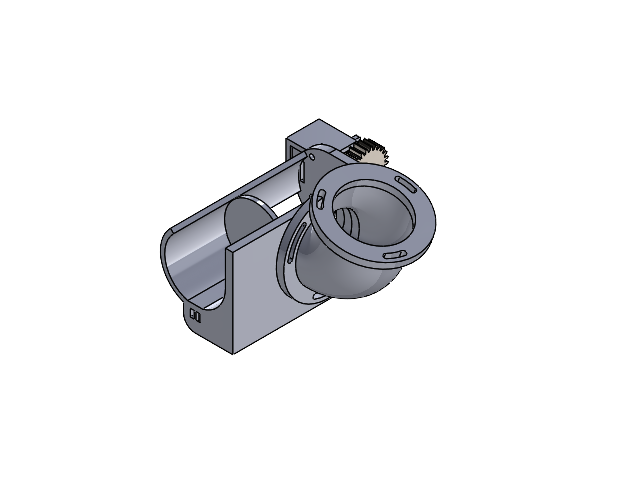
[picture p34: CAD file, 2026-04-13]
hardware/launcher/v1/launcher assembly/launcher assembly.SLDASM
Tube
Plunger
spur gear_iso
SG90-Servo
servo mount
barrel2storage

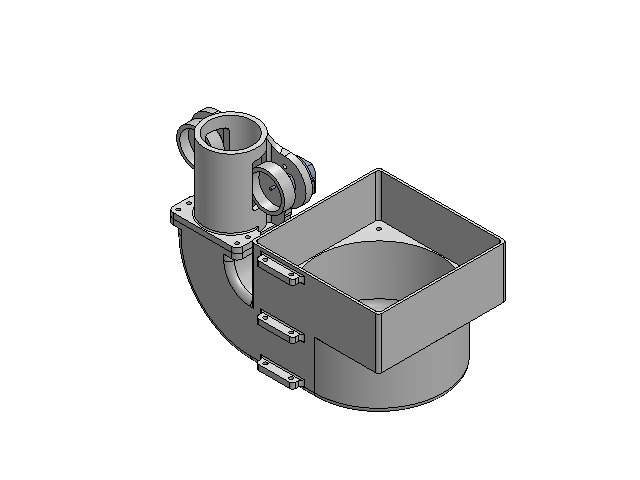
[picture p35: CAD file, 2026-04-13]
hardware/chassis/assembly/Launcher Assembly.SLDASM
Flywheel dummy x 2
Barrel guide
Carousell
Motor x 2
Motor Clamp x 2
Stepper Dummy

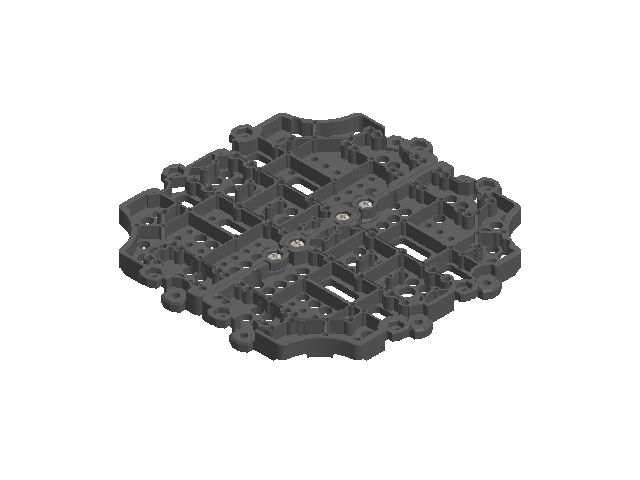
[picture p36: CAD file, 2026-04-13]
hardware/chassis/assembly/Waffle Layer2.SLDASM
Waffle Plate x 2
pan cross head_ks x 4
hexagon nut style 1 gradeab_ks x 4

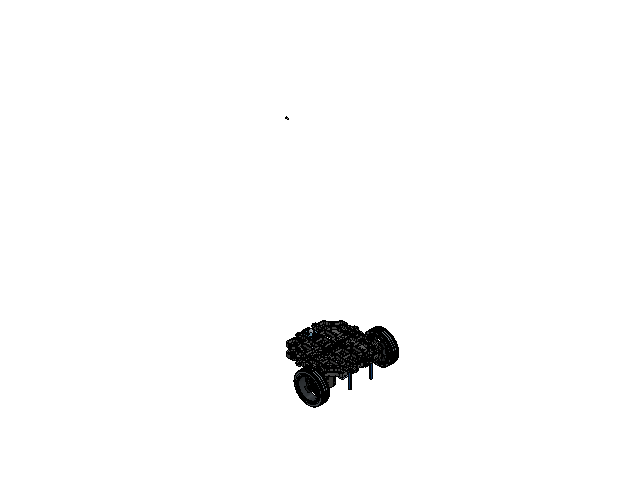
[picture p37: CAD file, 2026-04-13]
hardware/chassis/assembly/First Layer.SLDASM
STEELBALL_3_8INCH
PR21_CASTER_CVR_3X5_REV6
P30_ISP_A001_3D x 2
PR16_A01_TIRE_2 x 2
M_PR07_A01_BRACKET_2 x 5
SUPPORT_HEX_M3_0XL35_FF x 4
Waffle Plate x 2
pan cross head_ks x 28
hexagon nut style 1 gradeab_ks x 4
LB-012 Battery

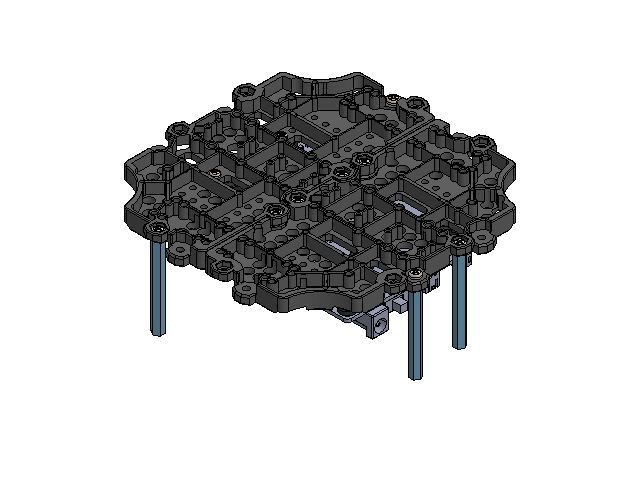
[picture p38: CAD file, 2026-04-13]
hardware/chassis/assembly/Second Layer.SLDASM
Waffle Plate x 2
pan cross head_ks x 8
hexagon nut style 1 gradeab_ks x 8
PR30_IBB_01_3D x 4
SUPPORT_HEX_M3_0XL45_FF x 4
OPENCR Dummy

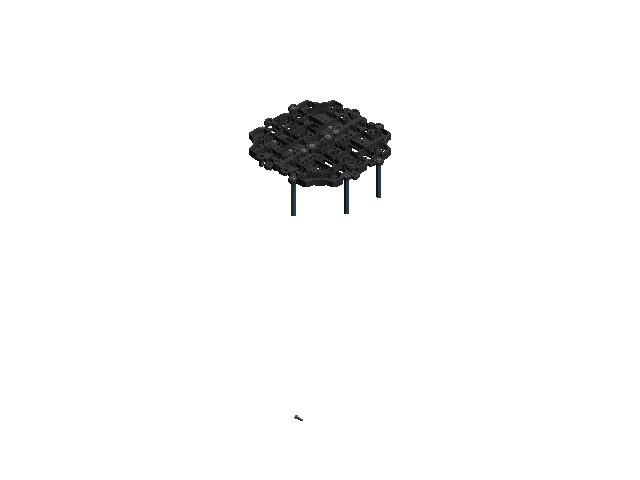
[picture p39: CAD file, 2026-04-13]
hardware/chassis/assembly/Third Layer.SLDASM
SUPPORT_HEX_M3_0XL45_FF-9 x 6
Waffle Plate x 2
pan cross head_ks x 18
hexagon nut style 1 gradeab_ks x 8
PR30_IBB_01_3D-10 x 4
Raspberry_Dummy
MICRO_USB
MICRO_USB-3
MICRO_USB-4
MICRO_USB-5
MICRO_USB-6
BIC04_C01_PCB
MICRO_USB-8

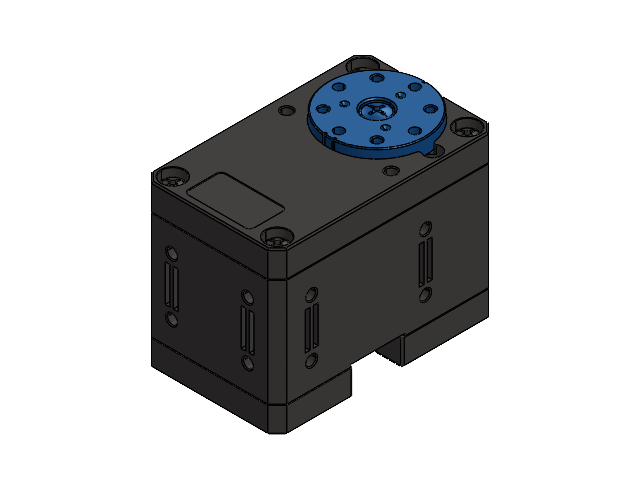
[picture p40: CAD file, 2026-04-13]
hardware/chassis/assembly/Dynamixel Motor.SLDASM


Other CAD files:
hardware/chassis/assembly/wheel _1_.SLDASM
hardware/chassis/assembly/ball_caster _1_.SLDASM
hardware/chassis/assembly/USB2LDS _1_.SLDASM
hardware/chassis/assembly/MICRO_USB-4.SLDPRT
hardware/chassis/3mf/launcher mount.3mf
hardware/chassis/3mf/mount to plate bottom.3mf
hardware/chassis/3mf/wire holder (end).3mf
hardware/chassis/assembly/530480810.SLDPRT
hardware/chassis/assembly/BIC04_C01_PCB.SLDPRT
hardware/chassis/assembly/LB-012 Battery.SLDPRT
hardware/chassis/assembly/MICRO_USB-3.SLDPRT
hardware/chassis/assembly/MICRO_USB-5.SLDPRT
hardware/chassis/assembly/MICRO_USB-6.SLDPRT
hardware/chassis/assembly/MICRO_USB-8.SLDPRT
hardware/chassis/assembly/MICRO_USB.SLDPRT
hardware/chassis/assembly/M_PR07_A01_BRACKET_2.SLDPRT
hardware/chassis/assembly/M_PR07_A01_SPACER_RIVET.SLDPRT
hardware/chassis/assembly/P30_ISP_A001_3D.SLDPRT
hardware/chassis/assembly/PR16_A01_TIRE_2.SLDPRT
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

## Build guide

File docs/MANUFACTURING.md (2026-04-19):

# Manufacturing

How to reproduce Group 7's 3D-printed parts on a **Bambu Lab P2S** using **Bambu Studio** default settings with **tree supports**.

## 1. Purpose & scope

This doc covers only the operator workflow for printing the `.3mf` files already in `hardware/`. It does **not** cover design rationale, version history, materials selection, or assembly — those live in [`../hardware/README.md`](../hardware/README.md).

Out of scope: custom slicer tuning, non-Bambu printers, filament other than Bambu PLA Basic, and post-print assembly (rack-pinion alignment, washer count, screw torque).

## 2. Required equipment

| Item | Spec / Notes |
|---|---|
| 3D Printer | Bambu Lab P2S (base or Combo) — 256 × 256 × 256 mm build volume, 0.4 mm hotend, textured PEI plate |
| Slicer | Bambu Studio, latest stable |
| Filament | Bambu PLA Basic (bundled preset). If using another PLA, re-select the filament profile but keep the process profile defaults |
| Plate | Textured PEI (shipped with the P2S) |
| Tools | Flush cutters, flexible scraper for PEI, small flathead for tree-branch removal |

Printer reference: <https://bambulab.com/en-us/p2s>
Slicer download: <https://bambulab.com/en/download/studio>

## 3. Parts list

All paths are relative to the repo root. **Current = part of the v2.2.0 deployed assembly. Legacy = earlier iteration kept for reference; do not print unless rebuilding a historical revision.**

### Chassis (current)

| File | Path | Subassembly | CAD source |
|---|---|---|---|
| `launcher mount v2.3mf` | `hardware/chassis/mounts/launcher mount v2.3mf` | Launcher-to-waffle-plate bracket (v2) | `launcher mount v2.SLDPRT` (same dir) |
| `RPI camera mount.3mf` | `hardware/chassis/3mf/RPI camera mount.3mf` | RPi camera mount (top deck) | — (no SLDPRT in chassis tree; v1 variant at `launcher/v1/launcher assembly/RPI camera mount.SLDPRT`) |
| `mount to plate bottom.3mf` | `hardware/chassis/3mf/mount to plate bottom.3mf` | Bottom mounting plate interface | — |
| `wire holder (end).3mf` | `hardware/chassis/3mf/wire holder (end).3mf` | Cable-management end-cap | — |

### Chassis (legacy, do not print for the current build)

| File | Path | Superseded by |
|---|---|---|
| `launcher mount.3mf` | `hardware/chassis/3mf/launcher mount.3mf` | `launcher mount v2.3mf` (see above) |

### Launcher (current — v2.2.0 deployed)

| File | Path | Subassembly | CAD source |
|---|---|---|---|
| `Plunger face.3mf` | `hardware/launcher/3mf/Plunger face.3mf` | Plunger face (ball-contact side; M3 bolted to rack) — v2.1.0+ split | — |
| `Plunger rack.3mf` | `hardware/launcher/3mf/Plunger rack.3mf` | Rack half of rack-and-pinion plunger — v2.1.0+ split | — |
| `barrel2storage.3mf` | `hardware/launcher/3mf/barrel2storage.3mf` | Barrel-to-storage-tube adapter | `launcher/v1/launcher assembly/barrel2storage.SLDPRT` |
| `spur gear for servo.3mf` | `hardware/launcher/3mf/spur gear for servo.3mf` | MG90 servo pinion (no clutch bearing; use for v2.0.0 / testing builds) (unconfirmed whether superseded by bearing variant in the deployed stack) | `launcher/v1/launcher assembly/spur gear for servo.SLDPRT` |
| `spur gear for servo with bearing.3mf` | `hardware/launcher/components/spur gear for servo with bearing.3mf` | Pinion with internal clutch-bearing pocket — **v2.2.0 deployed variant** | `components/spur gear for servo with bearing.SLDPRT` |

Additional launcher CAD (SLDPRT only, no `.3mf` in repo): `Barrel guide`, `Carousell`, `Clamp1/2`, `Motor Clamp`, `Part 1-14`, `Part 2-12`, `Part 3`, `Rotor` — all under `hardware/launcher/components/`. Their print status is **unconfirmed**; export STL/3MF from SolidWorks if you need them.

### Launcher (legacy v1.0.0)

Under `hardware/launcher/v1/launcher assembly/`. Kept for historical reference. Print **only** to reproduce the v1.0.0 side-mount configuration documented in [`../hardware/README.md#version-100---first-design`](../hardware/README.md#version-100---first-design).

| File | Path |
|---|---|
| `Plunger.3mf` | `hardware/launcher/v1/launcher assembly/Plunger.3mf` |
| `Tube.3mf` | `hardware/launcher/v1/launcher assembly/Tube.3mf` |
| `launcher assembly.3mf` | `hardware/launcher/v1/launcher assembly/launcher assembly.3mf` |

Versioned archives (`Launcher assembly 1.0.0.zip`, `Launcher assembly 1.1.0.zip`, `mounts 1.0.0.zip`) contain CAD snapshots for those releases and are not needed for printing.

## 4. Bambu Studio setup (one-time)

1. Install **Bambu Studio** from <https://bambulab.com/en/download/studio>. Create or sign in to a Bambu Lab account on first launch.
2. Put the P2S and your PC on the **same Wi-Fi SSID** (no guest network / client isolation). Run the on-printer setup wizard.
3. In Bambu Studio: **Device** tab → click **+** → Studio discovers the P2S → click it to bind to your account.
4. (Optional) On the printer: **Settings → WLAN → LAN Only Mode** on. A lock icon appears next to the device in Studio.
5. Confirm the default presets are available: printer **Bambu Lab P2S 0.4 nozzle**, filament **Bambu PLA Basic**, process **0.20 mm Standard @BBL P2S**.

## 5. Per-part print workflow

For every `.3mf` file in §3:

1. **Open** the `.3mf` in Bambu Studio (File → Open Project, or drag-and-drop). Accept the prompt to load the project's printer, filament, and process presets.
2. **Verify presets** in the top-right preset bar:
   - Printer: **Bambu Lab P2S 0.4 nozzle**
   - Filament: **Bambu PLA Basic**
   - Process: a **Standard** preset (typically 0.20 mm)
   - Plate: **Textured PEI Plate**
3. **Do NOT change** layer height, wall loops, infill density/pattern, speed, temperature, or plate type. "Default settings" here means *the bundled Bambu Studio P2S + PLA Basic preset, unmodified*.
4. **Enable tree supports**:
   - Left sidebar → **Support** tab.
   - Tick **Enable support**.
   - Set **Type** to **`tree(auto)`**.
   - Leave the sub-style on its default — Bambu Studio auto-selects **Tree Hybrid** when the process preset enables supporting material, otherwise **Tree Organic**. Do not override.
   - (Menu wording has been observed as both `tree(auto)` and `Tree (auto)` across Bambu Studio versions; either option is the intended one.)
5. **Slice** (top-right **Slice plate**). Inspect the preview:
   - First layer should fully cover the bed-contact face.
   - Tree branches should not pass through the part.
   - Estimated time / material should look reasonable for the geometry.
6. **Send to printer**: click **Print** → select the bound P2S. On first print per plate, enable **Bed Leveling** and **Flow Calibration**. Click **Send**.
7. **Alternative offline path**: **Export → Export plate sliced file (.gcode.3mf)** to microSD, insert into printer, print from the touchscreen.
8. **Observe the first layer** via the printer camera in Studio's **Device** tab. Abort if extrusion isn't clean.
9. **Remove the part** after cooldown: flex the PEI plate to pop it, then peel tree branches by hand. Use flush cutters at stubborn contact points — never pry with metal tools against PEI.

## 6. Part-specific notes

See [`../hardware/README.md`](../hardware/README.md) for why each part exists in its current form. Printing notes below are orientation and post-processing hints; none of them require overriding defaults.

| Part | Notes |
|---|---|
| `launcher mount v2.3mf` | Print flat against the plate as saved in the `.3mf`. v2 is the deployed variant; see [Version 2.0.0 — servo integrated into launcher](../hardware/README.md#version-200---servo-integrated-into-launcher). |
| `RPI camera mount.3mf` | Check lens-hole orientation before printing. No post-processing required beyond tree-support removal. |
| `mount to plate bottom.3mf` | Interfaces with the TurtleBot3 waffle plate. Verify mounting holes are at M3 clearance after print; drill/ream if needed. |
| `wire holder (end).3mf` | Cosmetic / strain-relief. Default infill is adequate. |
| `Plunger face.3mf` | v2.1.0+ split from the rack. Mates to `Plunger rack.3mf` with an M3 self-forming thread — do not over-tighten. See [Version 2.1.0 — bearing supports for rack and pinion](../hardware/README.md#version-210---bearing-supports-for-rack-and-pinion). |
| `Plunger rack.3mf` | Rack teeth are on the critical surface. If tree supports scar the teeth in the slicer preview, re-slice with **Normal (auto)** supports for this part only. Washers may be needed during assembly — see [Rack and pinion engagement](../hardware/README.md#rack-and-pinion-engagement). |
| `barrel2storage.3mf` | Barrel-side interfaces with the storage tube — verify bore diameter after print; ream if under-sized. |
| `spur gear for servo.3mf` | Non-bearing pinion. Use only for v2.0.0 / bench testing — the deployed v2.2.0 stack uses the bearing variant below. |
| `spur gear for servo with bearing.3mf` | **Deployed v2.2.0 pinion.** Internal pocket for INA HF 1012 clutch bearing + IKO LRT 61010 inner ring (press-fit after print). See [Clutch bearing reset](../hardware/README.md#clutch-bearing-reset). Sand the bore lightly if press-fit is too tight. |
| `Plunger.3mf` (v1) | Legacy single-piece plunger (pre-split). Do not print for the current build. |
| `Tube.3mf` (v1) | Legacy tube. Do not print for the current build. |
| `launcher assembly.3mf` (v1) | Legacy multi-part plate. Do not print for the current build. |
| `launcher mount.3mf` (legacy) | Superseded by `launcher mount v2.3mf`. Do not print for the current build. |

## 7. Troubleshooting

| Symptom | Likely cause / fix |
|---|---|
| First layer won't stick, part pops off | Plate type in slicer must match physical plate (**Textured PEI**). Clean plate with warm water + dish soap (no acetone, no moisturizer soaps). Run **Bed Leveling** from the printer utility menu. Try +5 °C bed. |
| Tree supports won't detach / tear the part | Increase **top z-distance** by one layer for that part only, or re-slice with **Normal (auto)** supports. Never pry with metal tools against PEI. |
| Rough underside on an overhang | Known tree-support artefact. Re-slice that part with **Normal (auto)** supports. |
| Nozzle clog / under-extrusion / clicking extruder | Run **Nozzle Cleaning** from the printer utility menu, then **Flow Dynamics Calibration** before retrying. |
| Model looks rotated in the `.3mf` | Do not re-orient — the author saved it that way. Re-orienting forces support regeneration and may change the critical surface. Confirm with the team before rotating. |
| Slicer warns about AMS slots on a base P2S | Base P2S has no AMS port. Ignore the warning and feed from the external spool holder. On a P2S Combo, match each filament slot by colour before sending. |

## 8. References

- [`../hardware/README.md`](../hardware/README.md) — Daniel's mechanical design doc: system description, v1.0.0 → v2.2.0 history, clutch-bearing mechanism, materials, limitations.
- Bambu Lab P2S product page — <https://bambulab.com/en-us/p2s>
- Bambu Lab P2S specifications — <https://bambulab.com/en/p2s/specs>
- Bambu Studio download — <https://bambulab.com/en/download/studio>
- Bambu Studio Quick Start — <https://wiki.bambulab.com/en/software/bambu-studio/studio-quick-start>
- Bambu Studio Support settings (tree types) — <https://wiki.bambulab.com/en/software/bambu-studio/support>
- First layer troubleshooting — <https://wiki.bambulab.com/en/knowledge-sharing/first-layer-not-sticking>
- Textured PEI plate care — <https://wiki.bambulab.com/en/general/textured-PEI-plate-not-working-as-expected>

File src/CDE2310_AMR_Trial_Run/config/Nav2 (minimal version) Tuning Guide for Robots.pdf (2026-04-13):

### Part 1: The Controller (Regulated Pure Pursuit)

RPP is your steering wheel. It works by projecting a "carrot" down the global path and steering the robot toward it.
- desired_linear_vel
- Normal Range: 0.15 to 0.22 m/s.
- The Reality: Do not push a small educational base past 0.25 m/s. The motors lack the torque to stop instantly, and fast movements will distort the online SLAM map due to rolling shutter on the LiDAR. Keep it slow and steady for staging.
- lookahead_dist
- Normal Range: 0.3 to 0.6 meters.
- The Reality: This is the most critical parameter in the entire file. It dictates how far ahead the robot places its carrot.
- max_allowed_time_to_collision_up_to_carrot
- Normal Range: 1.0 to 2.0 seconds.
- The Reality: This is your dynamic obstacle safety net. It projects the robot's velocity forward. If it detects a collision within this time frame, it slams on the brakes.
- transform_tolerance
- Normal Range: 0.2 to 0.5 seconds.
- The Reality: When the CPU spikes (e.g., SLAM is processing a loop closure), the TF tree lags. If this is too low, the controller instantly crashes with an "Extrapolation Error." Set it to 0.5 to give the system breathing room.

### Part 2: The Costmaps (The Danger Zones)

Costmaps dictate where the robot thinks it is safe to drive. 90% of navigation failures stem from poorly tuned inflation layers.
- robot_radius
- Normal Range: Exact physical radius + 0.02m safety margin (Usually 0.12 to 0.17 for small bases).
- The Reality: Do not lie to the costmap. If you make this artificially large to "be safe," the robot will refuse to enter doorways. If you have an asymmetrical robot, you must use footprint: [[x, y], ...] instead of robot_radius.
- inflation_radius
- Normal Range: 0.4 to 0.7 meters.
- The Reality: This determines how far the "danger gradient" spreads out from a wall. It should be large enough to gently push the robot toward the center of hallways.
- cost_scaling_factor
- Normal Range: 2.0 to 5.0.

- The Reality: An inverse scale. A higher number creates a steeper drop-off in cost. If you set this high, the robot will drive closer to obstacles. If you set it low, the cost spreads far out, and the robot will drive strictly down the center of open spaces.
- update_frequency (Local Costmap)
- Normal Range: 5.0 Hz.
- The Reality: Do not increase this to 10Hz or 20Hz. Processing a voxel grid of live LiDAR scans is computationally expensive. 5Hz is plenty fast enough to dodge a person walking.

### Part 3: The Staging Handoff (Goal Checker)

Because you built a custom, precision geometric docking server, Nav2 does not need to be highly accurate.
- xy_goal_tolerance & yaw_goal_tolerance
- Normal Range: 0.15 to 0.25 (meters/radians).
- The Reality: Do not demand 2cm accuracy from Nav2. If you set this to 0.02, Nav2 will violently wiggle back and forth for 10 seconds trying to hit the exact pixel before handing control to your docker. Loosen the tolerance. Let Nav2 get "close enough," and let your docker do the precision work.

### Part 4: Symptom & Troubleshooting Matrix

When the robot misbehaves, do not randomly change values. Identify the physical symptom and adjust the exact mathematical cause.
The Symptom | The Diagnosis | The Surgical Fix
The "Snake" / Oscillation The robot wiggles violently left and right while driving down a straight path. | The "carrot" is too close to the robot, causing an over-correction feedback loop. | Increase lookahead_dist by increments of 0.1m until it smooths out.
Corner Cutting The robot turns too early and clips the inside wall of a corner. | The "carrot" is too far away, causing the robot to drive diagonally across the corner. | Decrease lookahead_dist. Alternatively, increase inflation_radius on the global costmap to push the path further from the wall.
The Freeze The robot stops moving completely and throws "Failed to find valid control" warnings, even in open space. | The Local Costmap has "ghosts" (stale LiDAR data) blocking the robot, or TF transform lag has broken the controller. | 1. Ensure clearing: True in the obstacle layer. 2. Increase transform_tolerance to 0.5s. 3. Check if

| | max_allowed_time_to_collision is too high.
Doorway Refusal The global path routes cleanly through a gap, but the robot stops in front of it and won't enter. | The Local Costmap inflation gradient is too wide, merging the two sides of the door into a solid block of lethal cost. | Increase cost_scaling_factor (e.g., from 3.0 to 5.0) to make the cost gradient decay much faster around the doorframes.
Overshooting the Goal The robot drives past the Nav2 staging waypoint, stops, and has to reverse back into it. | desired_linear_vel is too high for the robot's physical deceleration profile, or the goal tolerances are impossibly tight. | Lower desired_linear_vel to 0.15 m/s. Loosen xy_goal_tolerance to 0.20m to allow an earlier success state.

Tune your costmaps first using RViz. Drive the robot manually with a joystick and watch the inflation gradients. If the costmaps don't reflect physical reality, the controller cannot save you.

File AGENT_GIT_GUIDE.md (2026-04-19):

# Agent Git Guide — Group7_AMR

Quick reference for AI assistants (Copilot, Claude, ChatGPT) working in this repo.

## Golden Rules

1. NEVER commit to `main`. Use `dev/<name>` branches only.
2. NEVER commit `build/`, `install/`, `log/`, `__pycache__/`, `.env`.
3. ALWAYS use conventional commit format.
4. ALWAYS add `ai-assisted: yes` footer when AI helped write the code.

## Branch Workflow

- Pull latest main before starting: `git pull origin main`
- Work on `dev/<name>` only (dev/jeon, dev/shashwat, dev/kuga, dev/clara, dev/daniel)
- Push to your branch, open PR targeting `main`, tag @jeonwonje as reviewer

## Commit Format

```
<type>(<scope>): <short description>

[optional body]

ai-assisted: yes
```

Types: feat, fix, docs, test, chore, refactor
Scopes: nav, explore, dock, delivery, perception, launcher, mission, hardware, report

## Colcon Workspace Rules

- Repo root IS the colcon workspace. Run `colcon build` from repo root.
- ROS2 packages live under `src/`. Non-ROS files in `hardware/`, `docs/`, `data/`.
- Incremental build: `colcon build --packages-select <pkg>`
- After build: `source install/setup.bash`
- COLCON_IGNORE files keep non-ROS dirs out of the build.

## Package Map

| Package | Scope | Contains |
|---|---|---|
| CDE2310_AMR_Trial_Run | mission | Mission coordinator FSM, docking, delivery, search, launcher, shooter nodes |
| auto_explore_v2 | explore | BFS frontier detection, scored Nav2 goal posting |

## Git Worktrees (for reviewers)

```bash
# Create a review worktree
git worktree add ~/worktrees/dev-clara dev/clara
cd ~/worktrees/dev-clara && colcon build && source install/setup.bash

# Remove when done
git worktree remove ~/worktrees/dev-clara
```

## PR Checklist

- [ ] Branch is up to date with main
- [ ] `colcon build` passes
- [ ] Commit messages follow conventional format
- [ ] AI-assisted footer present if AI was used
- [ ] CHANGELOG.md updated

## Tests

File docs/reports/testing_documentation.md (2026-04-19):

# Testing Documentation

| Field | Value |
|---|---|
| Document ID | AMR-TST-001 |
| Version | 1.0 |
| Date | 2026-04-13 |
| Author(s) | Group 7 — Jeon, Shashwat, Kuga, Clara, Daniel |
| Module | CDE2310 Engineering Systems Design |
| Status | Baselined for G2 |

---

## 1  Purpose

This document defines the test strategy, test cases, and known defects for
the Group 7 AMR. It covers unit, integration, and system-level testing aligned
with the requirements in AMR-RS-001.

---

## 2  Test Strategy

| Level | Scope | Tools | Automated? |
|---|---|---|---|
| Unit | Individual functions / algorithms | pytest | Yes |
| Lint / Style | PEP 8 compliance, docstrings | flake8, pep257 | Yes |
| Integration | Node-to-node communication (topics, svc) | Manual + ros2 CLI | Partial |
| System (FAT) | Full mission end-to-end | Physical maze run | No |
| Simulation | Gazebo world smoke tests | Gazebo + RViz | No |

---

## 3  Unit & Lint Tests

Unit coverage is currently limited to the ament lint / style scaffolds that
ship inside each Python package. The mission stack does not yet include
algorithm-level unit tests. All shipped tests run via `colcon test` and are
reported through `colcon test-result --verbose`.

| Package | Test files | Checks |
|---|---|---|
| auto_explore_v2 | `test/test_copyright.py`, `test_flake8.py`, `test_pep257.py` | Copyright header, flake8, pep257 |
| CDE2310_AMR_Trial_Run | `test/test_copyright.py`, `test_flake8.py`, `test_pep257.py` | Copyright header, flake8, pep257 |
| apriltag_docking | `ament_lint_auto` + `ament_lint_common` (via `package.xml`) | C++ lint suite |

**Known gap.** Deeper unit coverage for the pathfinding / frontier scoring
logic (`auto_explore_v2`), docking geometry (`docker.py`), and mission FSM
transitions (`mission_coordinator_v3.py`) is planned but not yet implemented.
Algorithm-level validation is currently performed through the integration and
system tests in §4 and §5.

---

## 4  Integration Test Plan

### 4.1  Test Cases

| ID | Title | Preconditions | Steps | Expected Result | Traces to  |
|---|---|---|---|---|---|
| TST-INT-01 | Exploration publishes frontiers | Cartographer running, /map available | 1. Launch `auto_explore.launch.py`<br>2. Monitor `frontiers` topic | Frontier JSON published within 5 s | FR-EXP-02  |
| TST-INT-02 | AprilTag TF broadcast | RPi camera running, tag visible | 1. `ros2 launch apriltag_docking apriltag_dock_pose_publisher.launch.py` on RPi<br>2. Hold tag in front of camera<br>3. `ros2 run tf2_ros tf2_echo camera tag36h11:0` | Transform printed with age < 0.5 s | FR-DET-02  |
| TST-INT-03 | toggle_exploration service | score_and_post running | 1. `ros2 service call toggle_exploration SetBool "{data: false}"`<br>2. Verify no new goal_pose<br>3. Re-enable with `{data: true}` | Goals pause and resume correctly | FR-MSN-01  |
| TST-INT-04 | delivery_server fires servo via GPIO | delivery_server running on RPi | 1. Send START_DELIVERY command<br>2. Observe MG90 servo activation on GPIO 12 | Servo fires, ball launched | FR-DEL-03  |
| TST-INT-05 | mission_command → docker | docker node running | 1. Publish `START_DOCKING` JSON on `/mission_command`<br>2. Monitor docker logs | Docker enters STAGING state | FR-DCK-01  |
| TST-INT-06 | DDS cross-machine topic flow | Both machines on same Wi-Fi | 1. RPi: publish test String on /test_topic<br>2. Laptop: echo /test_topic | Message received within 1 s | NFR-08 |

### 4.2  Integration Test Execution

Integration tests are performed manually during lab sessions. Results are
recorded in the test log (Section 7).

---

## 5  System Test Plan (Factory Acceptance Test)

### 5.1  FAT Checklist

The FAT simulates a full mission run in the lab maze. Each item must pass for
the system to be considered mission-ready.

| ID | Criterion | Pass Condition | Traces to |
|---|---|---|---|
| TST-SYS-01 | Full maze exploration | ≥ 90% occupancy grid coverage within 15 min | FR-EXP-01–05 |
| TST-SYS-02 | Tag detection during exploration | Both station tags detected and TF published | FR-DET-01–03 |
| TST-SYS-03 | Docking at Station A | Robot stops within 0.10 m, Y error ≤ 0.03 m | FR-DCK-01–02 |
| TST-SYS-04 | Static delivery (3 balls) | 3 balls fired at Station A | FR-DEL-01 |
| TST-SYS-05 | Docking at Station B | Same criteria as TST-SYS-03 | FR-DCK-01–02 |
| TST-SYS-06 | Dynamic delivery (target tag) | 3 balls fired reactively on dynamic tag detection | FR-DEL-02 |
| TST-SYS-07 | Mission completion | Coordinator reaches MISSION_COMPLETE state | FR-MSN-03 |
| TST-SYS-08 | Total time ≤ 25 min | Wall-clock time from start to MISSION_COMPLETE | NFR-01 |
| TST-SYS-09 | No manual intervention | Operator does not touch robot or keyboard post-start| CON-07 |
| TST-SYS-10 | Blacklist recovery | If dock fails, robot resumes exploration, retries later | FR-DCK-03  |
| TST-SYS-11 | Search fallback | If tag missed during exploration, search phase finds it | FR-MSN-02  |
| TST-SYS-12 | Emergency stop | LiDAR stop_distance (0.25 m) prevents wall collision | NFR-05 |

---

## 6  Known Issues & Defects

References: GitHub Issues #5–#8

| Issue # | Title | Severity | Status | Component | Description |
|---|---|---|---|---|---|
| #5 | Camera flicker causes false tag detections | Medium | Mitigated  | apriltag_docking / mission_coordinator | Rapid lighting changes cause frame-level false positives. Mitigated by stale TF threshold (0.5 s). |
| #6 | Nav2 goal rejection near map boundaries | Medium | Mitigated  | docker.py | Staging waypoints near map edges sometimes rejected. Mitigated by fallback_staging_offset. |
| #7 | Time offset drift between RPi and laptop | Low | Open | System-wide | Manual ~0.40 s offset occasionally drifts. No NTP configured. Stale TF threshold absorbs most drift. |
| #8 | Feed tube indexing unreliable after 6th ball | Low | Open | launcher (mechanical) | Gravity-fed tube occasionally jams near the last ball. Not mission-critical (7-ball capacity with 6 needed). |

---

## 7  Test Results Template

### 7.1  Lint / Style Test Log

| Date | Tester | Package | flake8 | pep257 | copyright | Notes |
|---|---|---|---|---|---|---|
| 2026-04-XX | — | auto_explore_v2 | — | — | — | |
| 2026-04-XX | — | CDE2310_AMR_Trial_Run | — | — | — | |

### 7.2  Integration Test Log

| Date | Tester | Test ID | Result | Notes |
|---|---|---|---|---|
| 2026-04-XX | — | TST-INT-01  | PASS / FAIL | |
| 2026-04-XX | — | TST-INT-02  | PASS / FAIL | |
| 2026-04-XX | — | TST-INT-03  | PASS / FAIL | |
| 2026-04-XX | — | TST-INT-04  | PASS / FAIL | |
| 2026-04-XX | — | TST-INT-05  | PASS / FAIL | |
| 2026-04-XX | — | TST-INT-06  | PASS / FAIL | |

### 7.3  System Test (FAT) Log

| Date | Tester | FAT Run # | TST-SYS-01 | TST-SYS-02 | TST-SYS-03 | TST-SYS-04 | TST-SYS-05 | TST-SYS-06 | TST-SYS-07 | TST-SYS-08 | TST-SYS-09 | TST-SYS-10 | TST-SYS-11 | TST-SYS-12 | Overall | Notes |
|---|---|---|---|---|---|---|---|---|---|---|---|---|---|---|---|---|
| 2026-04-XX | — | 1 | — | — | — | — | — | — | — | — | — | — | — | — | — | |

---

## 8  Revision History

| Version | Date | Author | Changes |
|---|---|---|---|
| 1.0 | 2026-04-13 | Jeon | Initial baseline |

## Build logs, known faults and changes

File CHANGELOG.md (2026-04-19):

# Changelog

All notable changes to this project will be documented in this file.

The format is based on [Keep a Changelog](https://keepachangelog.com/en/1.1.0/),
and this project adheres to [Semantic Versioning](https://semver.org/spec/v2.0.0.html).

## [Unreleased]

### Added
- Gazebo simulation support: maze world, AprilTag models, full-mission sim launch (`gazebo_mission.launch.py`).
- `nav_tuner.launch.py` and `slam_test.launch.py` for isolated Nav2 and SLAM tuning.
- Mechanical hardware documentation completed in `hardware/README.md`.
- `apriltag_docking` ROS 2 package (`src/apriltag_docking/`): custom RPi-side perception pipeline composing `camera_ros`, `image_proc` (resize + rectify), and `apriltag_ros` into a zero-copy container, plus per-station static dock-target TF frames and `detected_dock_pose_publisher` nodes that publish `/detected_dock_pose_{0,2}` (PoseStamped) consumed by the Nav2 docker.
- `docs/MANUFACTURING.md`: operator-facing Bambu Lab P2S `.3mf` print workflow for reproducing the team's 3D-printed parts (default Bambu Studio preset + tree supports), linked from the slim README and complementing Daniel's `hardware/README.md`.

### Changed
- Nav2 global planner switched to Dijkstra; global and local costmap inflation radii split and retuned for tight corridors.
- Documentation rewritten against the actual codebase: removed references to non-existent nodes (`apriltag_detector`, `launcher_node`, `rpi_shooter_node`, `static_station`, `auto_nav`). AprilTag detection now lives in the team-authored `apriltag_docking` package, which wraps the upstream `apriltag_ros` detector.
- `README.md` reduced from ~585 lines to a ~70-line doc index pointing at the split SDD under `docs/reports/`; all intra-README anchor links dropped.
- End User Documentation rewritten for the printed 5-page Final Mission hand-in: corrects platform (Burger, not Waffle Pi), actuator (XL430-W210), ball capacity (7, not 3), docking distances (staging 0.40 m / stop 0.10 m), and deployment flow (2 terminals, not 7). §3 Acceptable Defect Log and §5 Maintenance & Part Replacement Log populated.
- Subsystem Design §4.3 Docking expanded from a 3-phase description to the real 8-state FSM in `docker.py` (IDLE → NAV_TO_STAGING → COMPUTE_GEOMETRY → INTERCEPT → SQUARE_UP → EVALUATE_POSITION → RETRY_BACKUP → FINAL_PLUNGE → UNDOCKING).
- Mission FSM diagrams: removed phantom "map exhausted" branch. Documented the real transitions — exploration-timeout to SEARCH (480 s default), master-timeout to MISSION_TIMED_OUT (1200 s), all-stations-serviced to MISSION_COMPLETE. `EXPLORATION_COMPLETE` / `"explorer"` status values in the ICD are now annotated as dangling contracts (never emitted by any node).
- Hardware-Software Mapping: removed non-existent buck converter; RPi is powered directly by the OpenCR 5 V regulator (NFR-07, ICD GND row, HLD Layer-1 diagram).
- Tag edge length corrected from 0.16 m to 0.0986 m across all reports (per `apriltag_docking/config/apriltags_36h11.yaml`).
- ICD TF tree redrawn with the real `camera_link → camera → tag36h11:{0,2} → nav2_dock_target_{0,2}` chain; bogus `tag36h11:3` TF branch removed (tag 3 is inspected via `/detections` only, never broadcast as a frame).
- ICD topic table: added `/detected_dock_pose_{0,2}`, `/camera/resized/{image_raw,camera_info,image_rect}`, and `/camera/camera_info`; corrected publisher for `/detections`. ICD services: added `clear_blacklist` (std_srvs/Empty, score_and_post → mission_coordinator).
- Testing §3 Unit & Lint Tests consolidated and honest: unit coverage is limited to ament lint scaffolds; pathfinding / frontier-scoring / docking-geometry suites flagged as planned-but-unimplemented (TST-UT-01…29 phantom rows removed).
- Software Development §Dependencies split into Team Packages and Upstream Deps, reflecting `apriltag_docking` as team-authored with the full upstream list pulled from its `package.xml`. AI-attribution section bumped to Claude Opus 4.7.
- Subsystem Design §2.6 Search: `max_safe_search_radius` doc-code mismatch fixed (0.6 m per `search_stations.py:35`, previously documented as 1.5 m).

### Fixed
- Reverted a Gazebo-only tuning of `minimal_nav2.yaml` that had degraded real-robot behaviour.

## [1.2.0] - 2026-04-17

### Added
- Consolidated `delivery_server` node (`delivery_server_consolidated.py`) handling both static timed delivery (tag 0) and dynamic tag-3 reactive firing on the RPi.
- `gazebo_mission.launch.py` integrating TurtleBot3 spawn, Cartographer, Nav2, and the full mission stack in simulation.
- `fire_test.py` servo-preload bench utility.
- Semver release tags (`v1.0.0`, `v1.1.0`, `v1.2.0`).
- README rewritten as the single consolidated project document (architecture, launch instructions, end-user documentation).

### Changed
- Mission timeout management centralised in `mission_coordinator_v3` (replaces per-subsystem timers).
- Nav2 controller retuned for tight corridors: raised angular velocity/acceleration caps, tightened inflation radius.
- Docking and search-zone parameters refined after live-robot testing.

### Removed
- **Breaking:** separate `launcher_node` and `rpi_shooter_node` modules — functionality merged into `delivery_server_consolidated`. The `/fire_ball` service and shooter-node launch wiring no longer exist.

## [1.1.0] - 2026-04-13

### Added
- G2 systems engineering documentation under `docs/reports/`: ConOps, requirements specification, high-level design, subsystem design, interface control document, software development plan, testing documentation.
- End-user documentation under `docs/end_user_doc/`.

### Fixed
- Missing console-script entry points added to `setup.py`.

### Removed
- **Breaking:** legacy scaffold packages `amr_navigation`, `amr_perception`, `amr_launcher`, `amr_bringup`, `amr_utils`, and the later `amr_nav` package — superseded by `CDE2310_AMR_Trial_Run` and `auto_explore_v2`. The 29 pathfinding unit tests from `amr_nav/test/test_pathfinding.py` are recoverable from git history (commit `044e346`) but are no longer shipped.
- `archive/` directory.

## [1.0.0] - 2026-04-13

Initial integrated-system release. First end-to-end assembly of navigation, exploration, docking, delivery, and mission coordination.

### Added
- `auto_explore_v2` package: BFS frontier detection (`find_frontiers`) and frontier scoring with Nav2 goal posting plus `ComputePathToPose` pre-flight validation (`score_and_post`).
- `CDE2310_AMR_Trial_Run` package:
  - `mission_coordinator` FSM orchestrating explore → dock → deliver → undock → search.
  - `docking_server` — discrete geometric visual-servoing state machine (stage → intercept → square-up → plunge) with blacklist-on-failure.
  - `search_stations` — zone-sweep fallback with 360° scans.
  - `delivery_server`, initial `launcher_node`, and RPi shooter node for servo PWM ball delivery (later consolidated in 1.2.0).
  - Static and dynamic station handling.
- Cartographer SLAM config, minimal Nav2 params, and launch files (`mission.launch.py`, `full_mission.launch.py`, `minimal_nav2.launch.py`).
- Early custom Dijkstra/A* exploration implementation — superseded by the Nav2 + BFS scoring stack above.
- TurtleBot3 assembly CAD (`hardware/chassis/`) and launcher mechanism CAD — barrel, plunger (face + rack), spur gear, V1/V2 prototypes (`hardware/launcher/`).
- 3MF manufacturing files for 3D printing.
- Repository scaffolding: `src/`, `hardware/`, `docs/`, `data/`; `CLAUDE.md`, `AGENT_GIT_GUIDE.md`, `README.md`, `.gitignore`, `requirements.txt`.

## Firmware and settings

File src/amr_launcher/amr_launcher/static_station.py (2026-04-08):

import RPi.GPIO as GPIO
import time
import rclpy
from rclpy.node import Node
from std_srvs.srv import Trigger

SERVO_PIN = 12
TIME_PER_REV = 0.87
CCW = 10.0

class ShooterService(Node):
    def __init__(self):
        super().__init__('shooter_service')
        self.srv = self.create_service(Trigger, 'shoot', self.shoot_callback)
        
        GPIO.setmode(GPIO.BCM)
        GPIO.setwarnings(False)
        GPIO.setup(SERVO_PIN, GPIO.OUT)
        self.pwm = GPIO.PWM(SERVO_PIN, 50)
        self.pwm.start(0)
        
        self.get_logger().info('Shooter service ready')

    def shoot_callback(self, request, response):
        try:
            self.get_logger().info('Firing sequence started')

            self.get_logger().info('Round 1/3')
            self.fire_round()
            time.sleep(4)

            self.get_logger().info('Round 2/3')
            self.fire_round()
            time.sleep(6)

            self.get_logger().info('Round 3/3')
            self.fire_round()

            self.get_logger().info('Done!')
            response.success = True
            response.message = 'All 3 rounds fired successfully'

        except Exception as e:
            response.success = False
            response.message = str(e)

        return response

    def fire_round(self):
        self.pwm.ChangeDutyCycle(CCW)
        time.sleep(TIME_PER_REV)
        self.pwm.ChangeDutyCycle(0)

    def destroy_node(self):
        self.pwm.stop()
        GPIO.cleanup()
        super().destroy_node()


def main(args=None):
    rclpy.init(args=args)
    node = ShooterService()
    try:
        rclpy.spin(node)
    except KeyboardInterrupt:
        pass
    finally:
        node.destroy_node()
        rclpy.shutdown()

if __name__ == '__main__':
    main()

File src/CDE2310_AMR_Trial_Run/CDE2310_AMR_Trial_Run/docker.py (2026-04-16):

#!/usr/bin/env python3
import rclpy
import json
import math
from rclpy.node import Node
from rclpy.action import ActionClient
from rclpy.parameter import Parameter

from geometry_msgs.msg import Twist, PoseStamped
from nav2_msgs.action import NavigateToPose
from tf2_ros import Buffer, TransformListener
from tf2_ros import TransformException
from action_msgs.msg import GoalStatus
from std_msgs.msg import String
import tf2_geometry_msgs  

def euler_from_quaternion(q):
    siny_cosp = 2 * (q.w * q.z + q.x * q.y)
    cosy_cosp = 1 - 2 * (q.y * q.y + q.z * q.z)
    return math.atan2(siny_cosp, cosy_cosp)

class DockingServer(Node):
    """
        DockingServer: Discrete Geometric Visual Servoing Node

        --- GEOMETRIC DOCKING PARAMETERS TUNING GUIDE ---
        This node abandons continuous PID curves in favor of a discrete state machine. 
        Tuning is now primarily about geometric boundaries, not mathematical gains.

        1. The Geometry Limits (The "Runway")
        - intercept_ratio: (e.g., 0.6) The dynamic lookahead. If staging is 0.75m, the robot 
          aims to hit the centerline at 0.45m. Increase (0.7) for a sharper, earlier intercept. 
          Decrease (0.4) for a shallower, later intercept.
        - abort_ratio: (e.g., 0.3) The hard safety boundary. If the robot closes within 30% 
          of the staging distance and still hasn't cleared the Y-error, it aborts the slant 
          to prevent crashing into the tag.

        2. State Transition Tolerances
        - intercept_y_tolerance: (m) How close to the centerline the robot must be to consider 
          State 1 (INTERCEPT) complete. Keep this tight (0.02).
        - square_yaw_tolerance: (rad) How perfectly parallel the nose must be to the tag to 
          consider State 2 (SQUARE_UP) complete. 0.05 rad is ~3 degrees.
        - max_allowed_y_error: (m) The final gatekeeper evaluated in State 3. If Y-error is 
          higher than this after squaring up, it triggers a backup instead of plunging.

        3. Speeds and Gains
        - slow_linear_speed: (m/s) Constant forward speed used during INTERCEPT and FINAL_PLUNGE. 
          Keep this low (0.03) to minimize encoder slip and camera blur.
        - k_angular: Single proportional gain for all rotations (Square Up and tracking). 
          Increase if rotation is sluggish; decrease if the robot overshoots the centerline.
        - max_angular_speed: Absolute cap (rad/s) to prevent violent jerks.

        4. Nav2 Staging & Refinement
        - staging_distance: Meters in front of the tag where Nav2 drops the robot.
        - stop_distance: The exact distance (meters) from the camera lens to the tag to halt.
        - refinement_interval / refinement_cutoff: Limits how often the node spams Nav2 with 
          updated goals during the initial approach.
        - fallback_staging_offset: Distance subtracted if Nav2 rejects the initial staging goal.

        5. Robustness & Fallbacks
        - sensor_drop_tolerance: How long (seconds) to coast on memory during a camera flicker.
        - max_docking_time: Hard stopwatch (seconds) for the entire sequence to prevent hanging.
        - max_retries: Number of allowed backup attempts before settling.
        - backup_speed / backup_duration: Controls the exact distance of the safe retreat.
        """
    def __init__(self):
        super().__init__('docking_server')
        
        if not self.has_parameter('use_sim_time'):
            self.declare_parameter('use_sim_time', False)
        
        # --- DOCKING PARAMETERS ---
        self.staging_distance = 0.40       
        self.stop_distance = 0.10        

        # --- ROBUSTNESS PARAMETERS ---
        self.fallback_staging_offset = 0.15
        self.max_docking_time = 240.0        
        self.sensor_drop_tolerance = 1.0    
        
        # --- REFINEMENT PARAMETERS ---
        self.refinement_interval = 4.0    
        self.refinement_cutoff = 0.7     
        
        # --- GEOMETRIC DOCKING PARAMETERS ---
        self.intercept_ratio = 0.7        
        self.abort_ratio = 0.3            
        
        self.intercept_y_tolerance = 0.03 
        self.square_yaw_tolerance = 0.05  
        
        # --- SPEEDS AND GAINS ---
        self.slow_linear_speed = 0.03     
        self.k_angular = 2.0              
        self.max_angular_speed = 0.25
        
        # --- RETRY PARAMETERS ---
        self.max_retries = 3
        self.max_allowed_y_error = 0.05   
        self.backup_speed = -0.1         
        self.backup_duration = 3.0        

        # --- UNDOCKING PARAMETERS ---
        self.undock_distance = 0.20        
        self.undock_speed = -0.15         

        # Internal State Machine
        self.state = 'IDLE'
        self.target_tag = None
        self.target_frame = None
        self.current_retries = 0
        
        # Kinematics Memory
        self.current_x = 0.0
        self.current_y = 0.0
        self.current_yaw_error = 0.0
        
        self.tag_x_base = 0.0
        self.tag_y_base = 0.0
        self.tag_yaw_base = 0.0
        
        self.saved_target_pose_odom = None
        self.last_tag_sight_time = None
        self.is_blind = False
        self.initial_x_at_geometry = 0.0
        self.last_goal_update_time = None
        self.fallback_attempted = False
        
        # ROS 2 Interfaces
        self.cmd_vel_pub = self.create_publisher(Twist, '/cmd_vel', 10)
        self.nav_client = ActionClient(self, NavigateToPose, 'navigate_to_pose')
        self.status_pub = self.create_publisher(String, '/mission_status', 10)
        self.command_sub = self.create_subscription(String, '/mission_command', self.command_callback, 10)
        
        self.tf_buffer = Buffer()
        self.tf_listener = TransformListener(self.tf_buffer, self)
        
        self.timer = self.create_timer(0.05, self.tick) 
        self.get_logger().debug("Geometric Docking Server initialized.")
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

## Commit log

2026-04-06 added servo control
2026-04-15 feat(nav): add Gazebo maze, AprilTag models, Nav2 tuning for tight corridors
    - Custom amr_maze.world with 0.38m corridors, angled walls, AprilTag stations
    - AprilTag textured models (tag36h11 ID 0 and 2) for camera detection
    - Nav2 params tuned for 0.32m robot in tight corridors on WSL2:
    SmacPlanner2D, SimpleSmoother, RPP controller at 5Hz
    - Explorer startup delay + blacklist clearing to prevent premature completion
    - Gazebo launch: DDS loopback override, 30s lifecycle bond timeout
    - Search zones updated for Gazebo maze coordinates
    ai-assisted: yes
    [model.sdf]
2026-04-15 fix(nav): revert Gazebo-tuned params to real-robot config
    PR #14 merged with Gazebo-specific Nav2 params (SmacPlanner2D, 5Hz
    controller, 0.06 m/s) that break real robot operation. Restores:
    - NavfnPlanner A*, 16Hz controller, real-robot kinematic limits
    - Real arena search zones in search_stations.py
    - Removes Gazebo SLAM startup guards from score_and_post.py
    - Keeps angular vel/accel tuning (0.8/0.5) and inflation_radius (0.16)
    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
    [search_stations.py]
2026-04-15 tune(nav2): switch to Dijkstra, split global/local costmap inflation, add nav_tuner launch
    - Switch planner from A* to Dijkstra (use_astar: false) with cost_factor 0.35
    - Global costmap: cost_scaling_factor 3.5, inflation_radius 0.20, clearing disabled
    - Local costmap: cost_scaling_factor 9.0, inflation_radius 0.17
    - Lower lookahead_dist to 0.20m for tighter corner hugging
    - Drop planner frequency to 2Hz to prevent missed rate warnings
    - Add nav_tuner.launch.py (Cartographer + Nav2 + exploration + RViz, no mission nodes)
    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
2026-04-18 V1 | Tested
    updated final calibration values
2026-04-18 docs: purge phantom nodes and correct DDS/perception claims
    Grounds all reports and end-user docs in the actual codebase. Removes references
    to nodes that never shipped (apriltag_detector, launcher_node, rpi_shooter_node,
    static_station, auto_nav) and rewrites the perception subsystem to describe the
    external apriltag_ros package that the team actually uses. Corrects DDS claims
    from FastDDS to CycloneDDS (with FastRTPS Gazebo/WSL2 fallback), fixes sender
    strings on the mission status bus, aligns docking/search parameters with
    delivery_server + search_stations source, and rewrites CHANGELOG per SemVer
    against real main-branch history. Removes fabricated 29-test catalog from
    testing_documentat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
2026-04-19 feat(perception): add apriltag_docking ROS 2 package
    Custom RPi-side perception pipeline used by the docking server. Wraps
    camera_ros, image_proc (resize + rectify), and apriltag_ros in a single
    zero-copy composable container and adds:
    - Static TF broadcasters for base_link -> camera_link -> camera (optical).
    - Per-station static TF tag36h11:{0,2} -> nav2_dock_target_{0,2}.
    - detected_dock_pose_publisher (C++) that re-publishes each dock-target
    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
2026-04-19 docs(report): replace apriltag_ros with apriltag_docking across SDD
    Brings five SDD reports in line with the real code after merging the
    team's custom apriltag_docking package (prev. commit) and the recent
    DDS/perception cleanups on main.
    - Perception subsystem: rewrite every top-level reference from the
    upstream apriltag_ros package to the team-authored apriltag_docking
    wrapper (composable camera_ros + image_proc Resize + Rectify +
    apriltag_ros + detected_dock_pose_publisher pipeline on the RPi).
    apriltag_ros remains cited only as an upstream dep, not a top-level
    node.
    - Tag size corrected from 0.16 m to 0.0986 m (per apriltags_36h11.yaml).
    - Hardware-software mapping: drop non-e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
2026-04-19 docs(eud): rewrite for 5-page printed submission; align with real robot
    Full rewrite of the End User Document for the G2 Final Mission printed
    hand-in (5-page maximum, checked against the physical MeowthBot during
    the 25-minute mission window). Five mandatory sections per G2 spec:
    (1) General System Description & Critical Data, (2) Technical Guide,
    (3) Acceptable Defect Log, (4) Factory Acceptance Test, (5) Maintenance
    and Part Replacement Log.
    Corrections vs prior draft:
    - Platform: TurtleBot3 Burger (MeowthBot), not Waffle Pi.
    - Actuator: Dynamixel XL430-W210, not XM430-W210.
    - Ball capacity: 7 balls (3 Station A + 3 Station B + 1 spare), not 3.
    - Docking: staging 0.40 m, stop 0.10 m (pe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
2026-04-19 docs(changelog): record G2 doc rewrite + apriltag_docking addition
    Consolidates the [Unreleased] entry to reflect the full G2 rewrite pass:
    - apriltag_docking package addition (Added section)
    - MANUFACTURING.md (Added)
    - README trim + SDD split + EUD rewrite (Changed)
    - Docking 8-state FSM, mission FSM (map-exhausted removal, EXPLORATION_
    COMPLETE annotation) (Changed)
    - Power-path correction (no buck converter) (Changed)
    - Tag size 0.16 -> 0.0986 m (Changed)
    - ICD topic/service/TF corrections (Changed)
    - Testing phantom-unit-test removal (Changed)
    - max_safe_search_radius 1.5 -> 0.6 m (Changed)
    The previous [Unreleased] blurb had stated that AprilTag detection was
    provided by the externa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
2026-04-19 docs(eud): port printed-PDF branding and figures; bump to Document v2.1
    Applies the printed End User Documentation v2.0 (2026-04-16) styling
    to the repo-side markdown so a re-exported PDF carries the same cover,
    branding, and figure layout. Content remains code-truth from the
    previous docs(eud) commit — the PDF v2.0 is superseded, not restored.
    - Cover: "MeowthBot AMR" title under a "Group 7 Engineering Company
    Pte Ltd" banner, with the side-and-front robot photos (Figure 1)
    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
2026-04-19 docs(diagrams): add PlantUML source + rendered images for HLD §2
    First diagram in the UML rewrite pass. Replaces the ASCII architectural-
    overview block with proper vector output using the team's existing house
    style (extracted from software_uml_diagram.svg: Arial, #AED6F1/#2E86C1
    components, rounded corners, #2C3E50 thick arrows, skinparam roundCorner 20).
    Adds docs/diagrams/_style.iuml — shared PlantUML style include, so all
    subsequent diagrams inherit the same palette.
    Renders use PlantUML's built-in Smetana layout engine (!pragma layout
    smetana) so no Graphviz install is required.
    Not wired into high_level_design.md yet — awaiting visual review of all
    seven diagrams before the AS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
